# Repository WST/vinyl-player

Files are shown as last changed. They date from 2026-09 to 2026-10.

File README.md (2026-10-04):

# Мини-проигрыватель виниловых пластинок

Параметрические модели корпуса и механики небольшого проигрывателя под
7" пластинки. Всё считается в OpenSCAD, печатается на FDM-принтере.

Стадия: **прототип №0**. Принцип работы — сначала получить крутящийся диск и
играющий тонарм, потом улучшать. Поэтому здесь сознательно нет обратной связи
по скорости, микролифта и антискейтинга (см. [Отложено](#отложено)).

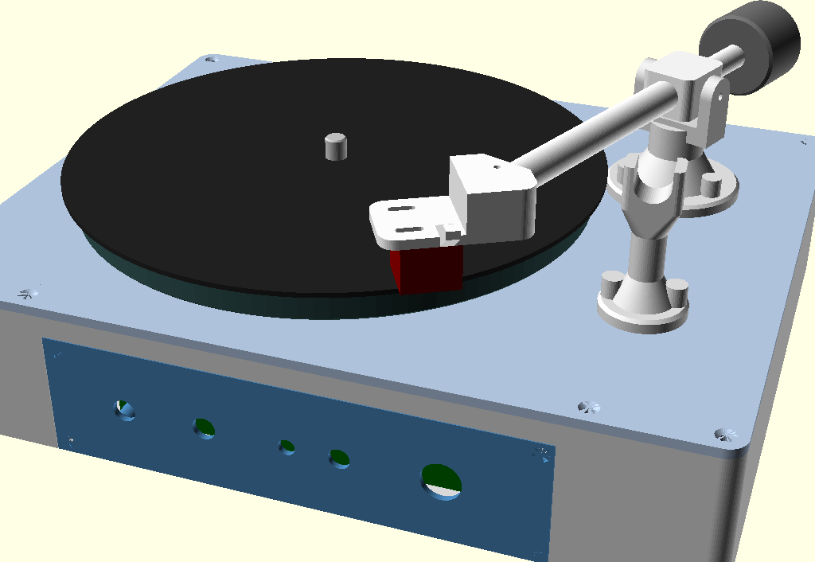
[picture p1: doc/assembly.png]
Общий вид


## Что уже заложено

| Узел | Решение |
|---|---|
| Корпус | 250 x 200 x 50 мм, стенки 2 мм, поддон + верхняя часть на саморезах |
| Скругления | только вертикальные (боковые) рёбра, R6; верх и низ — острые |
| Диск | 170 мм, только 7" пластинки |
| Модуль вращения | отдельный «плагин» на своём шасси, ставится в поддон на 4 бобышки |
| Вал диска | стальной пруток 8 мм на двух 608ZZ, конец сточен до 7.1 мм под пластинку |
| Привод | RF-300C-14270, две ступени пассиков 1.2 мм, редукция 90:1 |
| Тонарм | поворотный, эффективная длина 130 мм, головка AT91 |
| Головка | съёмная площадка: гнездо под трубку с прижимным винтом, провод протягивается |
| Панель управления | отдельная деталь-вставка в передней стенке |
| Ножки | не предусмотрены: клеятся свои |

## Геометрия (считается автоматически)

При открытии любого файла OpenSCAD печатает сводку в консоль:

```
Габарит корпуса: 250 x 200 x 50 мм
Верх диска Z=60, рабочая плоскость пластинки Z=62.6
Отсек модуля вращения: X -93..40, Y -68..86, Z 7..42
Тонарм: L=130, вынос=17.9, разворот=30.9, ось качания Z=86.6
Погрешность тонарма на r=84: -0.53 град, на r=53: -0.32 град
```

Файлы модуля вращения добавляют к этому свою сводку — см.
[Модуль вращения](#модуль-вращения).

Система координат общая для всех деталей: X — вдоль широкой стороны, Y — вдоль
глубины (минус — передняя стенка), Z — вверх от внешней плоскости дна поддона.
Поэтому `assembly.scad` — это просто перечисление деталей без сдвигов, а любая
деталь открывается отдельно и стоит «на своём месте».

В `params.scad` и `drive/drive_params.scad` есть блоки `assert`-ов: они
проверяют, что противовес не вылезает за стенку на всём ходе тонарма, что
модуль вращения не выходит из своего отсека, что колёса не задевают друг
друга и башни, что пассики есть в наборе и так далее. Если поменять параметр
«неудачно», OpenSCAD откажется рендерить и скажет, что не так.

## Файлы

```
params.scad             все размеры проекта, производные величины, проверки
lib/common.scad         вспомогательные модули (скруглённая коробка, стойки, пазы)
assembly.scad           сборка целиком + болванки плат, пластинки, головки
parts/
  tray.scad                 поддон
  top_cover.scad            верхняя часть корпуса
  control_panel.scad        панель кнопок и регуляторов
  platter.scad              диск
  tonearm_base.scad         стойка тонарма
  tonearm_pin.scad          палец вертикальной оси
  tonearm_yoke.scad         вилка
  tonearm_arm.scad          ступица + трубка + хвостовик
  tonearm_headshell.scad    съёмная площадка головки звукоснимателя
  tonearm_counterweight.scad противовес
  tonearm_rest.scad         подставка тонарма
drive/                  модуль вращения — самостоятельный «плагин»
  drive_params.scad         его параметры, производные, проверки, сводка
  drive_lib.scad            общие куски шкивов
  drive.scad                drive_module(): узел в сборе + болванки покупного
  drive_assembly.scad       превью узла отдельно от проигрывателя
  parts/
    drive_chassis.scad          шасси: плита + две башни под 608ZZ
    drive_spindle_pulley.scad   колесо вала диска
    drive_spacer.scad           шайба под ним
    drive_idler_pulley.scad     большое колесо промвала
    drive_idler_cap.scad        колпачок-бортик промвала
    drive_motor_holder.scad     держатель двигателя
```

```sh
make -j4              # все STL в build/
make build/platter.stl
make drive            # только детали модуля вращения
make check            # прогнать все модели, поймать ошибки и незамкнутость
```

## Модуль вращения

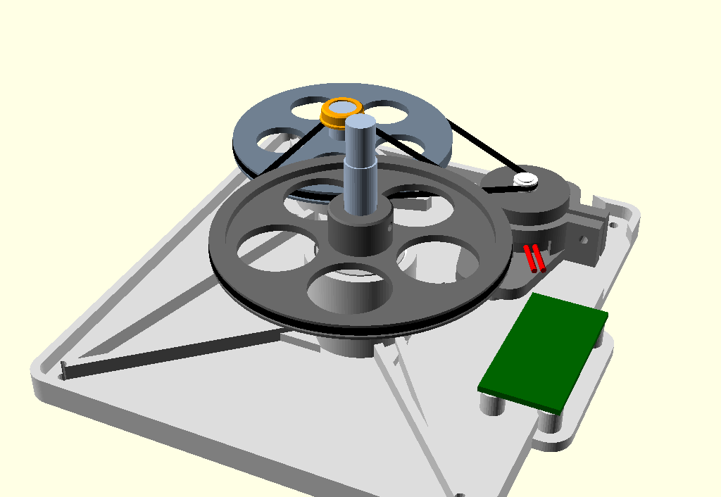
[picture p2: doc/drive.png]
Модуль вращения


### Зачем отдельный модуль

Привод — самая сырая часть проекта, её придётся переделывать много раз.
Поэтому всё, что крутит диск (вал, подшипники, колёса, двигатель), собрано на
собственном шасси и ставится в поддон как готовый узел — по аналогии с
панелью управления.

Поддон о приводе знает только **интерфейс**, он описан в `params.scad`:

* отсек `drive_bay`: от боковых стенок и передней стенки не ближе 30 мм (там
  будут динамики и плата управления), справа — до зоны тонарма и платы УМ;
* четыре бобышки `drive_mount_pos` под саморезы 2.5 x 8;
* потолок `drive_ceiling_z` — под рёбрами крышки, а в круге
  `spindle_keepout_d` вокруг вала, где рёбер нет, — почти до самой крышки;
* ось вала `platter_pos`, диаметр `spindle_d`, высота его верха.

Всё остальное живёт в `drive/`. Общая сборка вызывает только `drive_module()`
из `drive/drive.scad`. Другая реализация привода — это другая папка `drive/`
с тем же модулем и в тех же границах, поддон и крышка при этом не меняются.

Для работы с узлом есть `drive/drive_assembly.scad`: модуль в сборе, вокруг —
полупрозрачные поддон и разрешённый объём. Выключатели в начале файла:
диск сверху, разрез через оба вала и т.п.

### Кинематика

Двигатель RF-300C-14270 — около 3000 об/мин, диску нужно 33 1/3, то есть
редукция 90:1. Она разбита на две ступени:

1. **заводское колесо двигателя → большое колесо промвала** (62 мм), 11.3:1;
2. **промвал → колесо вала диска** (73.5 мм), 8:1. Здесь шкивом служит сам
   гладкий стальной промвал 8 мм, как тонвал в магнитофоне. Печатный шкив
   на валу получился бы минимум 11-12 мм — колёса выросли бы, а пассики
   перестали бы помещаться в набор.

Диаметры даны по средней линии пассика (дно канавки + толщина пассика).
Задаётся колесо промвала `idler_pulley_pd`, а колесо вала диска
пересчитывается так, чтобы при `motor_rpm` получалось ровно 33 1/3.
Межосевые и углы стоят в `drive_params.scad`, сводка при открытии любого
файла модуля:

```
Редукция: 11.3 x 8 = 90; двигатель 3000 -> промвал 266.1 -> диск 33.3 об/мин
Для 45 об/мин двигателю нужно 4050 об/мин
Колёса: промвал 62 мм (нар. 62.8), вал диска 73.5 мм (нар. 74.3)
Пассик 1: межосевое 55, путь 230.9 мм, охват 118 град -> брать ~107 по маркировке
Пассик 2: межосевое 58, путь 264.1 мм, охват 113 град -> брать ~123 по маркировке
Вал диска: пруток 8 мм длиной 66.1, сточить до 7.1 верхние 10.6 мм
Промвал: пруток 8 мм длиной 38
Плоскости пассиков: Z=31.2 и Z=36.7, дно двигателя Z=16.5 (дно держателя 3.5 мм)
```

**Пассики** — квадратные 1.2 мм из ремнабора. Маркировка таких наборов — это
«сложенная длина», половина окружности: самый большой «135» — это примерно
270 мм по кругу. Проверки требуют, чтобы оба пассика укладывались в 135 с
натягом 7 % (`belt_stretch`) и чтобы охват малых шкивов был не меньше 100
градусов. Если пассик не тянет, берётся следующий размер поменьше; первая
ступень дополнительно натягивается сдвигом держателя двигателя по пазам.

Скорость задаётся напряжением/ШИМ двигателя. Подбираются и 33, и 45 об/мин
(по стробоскопу или приложению-тахометру): двигатель допускает до 4 В, и
4050 об/мин для 45 укладываются с запасом.

### Валы и подшипники

Оба вала — отрезки стального прутка 8 мм, каждый в двух 608ZZ. Подшипники
запрессовываются в башни шасси: нижний — снизу, верхний — сверху, оба
упираются наружным кольцом в перемычку между гнёздами. Посадку гнезда правит
`brg_seat_clr`: проще напечатать пробную башню и подобрать.

Пруток проходит во внутреннее кольцо с зазором «в волос». Его надо выбрать,
иначе вал бьёт и может проворачиваться в кольце вместо подшипника. Модель
этого не решает, это делается при сборке:

1. **фольга** — один-два витка пищевой фольги (0.01-0.02 мм) на посадочном
   месте под каждым внутренним кольцом, без нахлёста по шву. Плотная посадка,
   полностью разборно — основной вариант, пока узел дорабатывается;
2. **кернение** посадочной шейки — 6-8 точек по окружности, выступы
   подогнать надфилем до тугой посадки;
3. **суперклей** — собрать насухо, выставить вал и капнуть жидкий клей на
   стык кольца с валом, его втянет в зазор. Разбирается только нагревом.

С фольгой порядок такой: вал с верхним подшипником вставляется сверху,
нижний подшипник надевается на вал снизу и запрессовывается одновременно на
вал и в гнездо — иначе фольга нижней посадки не пройдёт через верхнее кольцо.

По высоте вал зажат между двумя упорами, оба давят только на внутренние
кольца. Сверху — колесо: оно зажато на валу стопорным винтом M3 и через
шайбу `drive_spacer` (у промвала — пояском ступицы) стоит на верхнем
подшипнике. Снизу — кольцо из нескольких слоёв термоусадки под нижним
подшипником: не даёт вытянуть вал вверх, например вместе с диском. Через
верхний упор идёт и вес диска с пластинкой. Ступица колеса
поднимается в зону без рёбер крышки, поэтому винт оказывается над колесом,
и к нему есть подход сбоку. Верхний конец вала сточен до 7.1 мм: ступенька
прячется в ступице диска под матом, а сам диск зажимается своим стопорным
винтом уже на 8 мм.

У промвала колесо стоит сверху, а ступица уходит вниз, к подшипнику. Её
стопорный винт — под колесом. Над колесом — голый участок вала, по нему идёт
пассик 2. Снизу его ограничивает само колесо, сверху — напрессованный
колпачок `drive_idler_cap`. Участок вала под пассиком должен быть чистым,
без смазки — лучше слегка зашкурить для сцепления.

ZZ-подшипники с заводской смазкой заметно тормозят, а двигатель у нас
слабый (лучший КПД при ~3.8 г·см). Если не будет хватать момента — снять
пыльники с подшипников промвала, промыть их от смазки и капнуть жидкого масла.

### Двигатель

Держатель — стакан с хомутом: двигатель стоит в нём донцем, валом вверх,
обжимается стяжным винтом. Толщина дна держателя выставляет канавку
заводского колеса в плоскость пассика 1. Положение канавки
(`motor_groove_z`, 14.7 мм от донца) пока **оценочное — его надо измерить**.
Если оно другое, перепечатывается только держатель, шасси не меняется.
Провода выходят через вырез у дна стакана.

Рядом с двигателем, прямо напротив выреза под провода, на шасси стоят четыре
стойки под **плату регулятора оборотов** (около 20 x 40 мм): провода
двигателя получаются короткими и меньше наводят на звуковой тракт. Плата
вынесена из-под колеса вала диска, так что при снятой крышке к подстроечнику
можно подлезть сверху. Над платой остаётся ~24 мм под детали, под ней —
2.5 мм над рёбрами шасси под пайку выводов. Положение и отверстия задаются в
`drive_params.scad` (`reg_pcb_pos`, `reg_pcb_holes`). Отверстия по умолчанию
условные, их надо поправить под реальную плату — стойки сдвинутся, поддон
это не затрагивает. Стяжной винт хомута вворачивается со стороны, обратной
плате, чтобы плата не закрывала отвёртке подход.

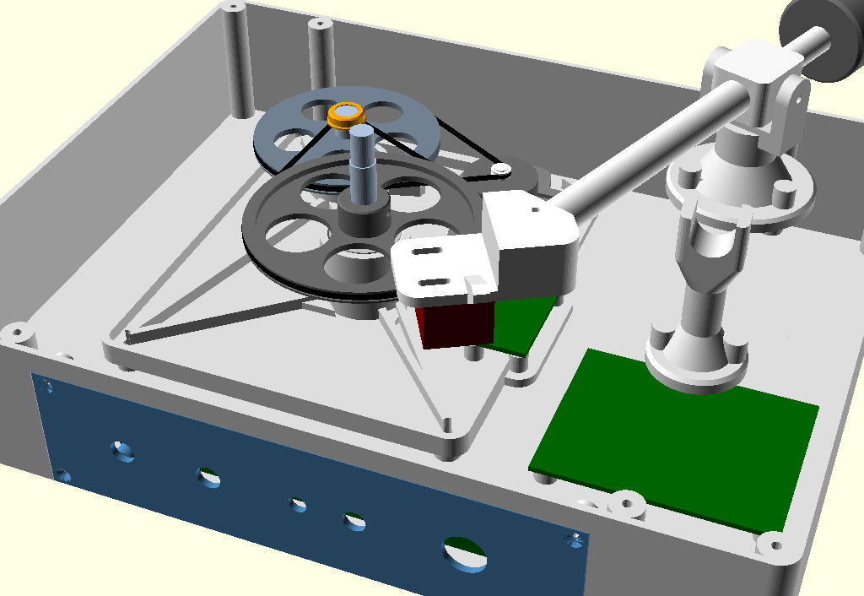
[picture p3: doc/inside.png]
Компоновка внутри


## Тонарм

Геометрия посчитана по Бервальду (Löfgren A) для рабочей зоны радиусов
53...84 мм, то есть под 7" сингл:

| Параметр | Значение |
|---|---|
| Эффективная длина (игла — ось) | 130 мм |
| Монтажное расстояние (ось — центр диска) | 112.1 мм |
| Вынос за центр диска | 17.9 мм |
| Разворот головки | 30.9 град |
| Нулевые точки | 56.0 и 77.4 мм |
| Максимальная погрешность тангенциальности | 0.57 град |

Трубка прямая, головка развёрнута. Угол между головкой и трубкой (около 40
град) и длина трубки не задаются руками, а выводятся из эффективной длины,
разворота и вылета головки — иначе при прямой трубке эти три величины
противоречат друг другу. Хочется другую длину тонарма — меняются
`arm_eff_len`, `arm_overhang`, `arm_offset_angle`, остальное пересчитается.

Кардан простейший: вертикальная ось — полый печатный палец в канале стойки со
смазкой, горизонтальная ось качания — два винта M3 с заточенными концами,
входящие в конусные гнёзда ступицы. Зазор выставляется глубиной завинчивания,
после настройки резьбу стоит зафиксировать лаком.

Площадка головки — **отдельная деталь**. Так сделано ради провода: пока
головка была единым целым с трубкой, канал оказывался заглушён её шеей и
завести провод было физически некуда. Теперь трубка открыта с торца, провод
протягивается насквозь до установки головки, а сама головка снимается — можно
поменять звукосниматель, не разбирая тонарм.

Сам стык предельно простой: на задней части площадки поднят «нарост» того же
контура, в нём наклонное гнездо под трубку, а задний угол срезан одной
плоскостью перпендикулярно трубке — это вход гнезда. Трубка входит на 9 мм до
упора в глухое дно и тянется винтом M2.5 сверху по лыске. Дно задаёт
эффективную длину, лыска — угол разворота, так что после снятия-установки
геометрия не уезжает.

Размеры площадки не выставлены руками: ширина, задний свес и высота нароста
проверяются assert'ами на то, что вход гнезда целиком лежит в контуре и что
вокруг него остаётся материал. Меняется угол разворота или диаметр трубки —
проверки скажут, что править. Подставка ловит трубку перед наростом, чтобы
вес тонарма ложился на саму трубку, а не на съёмную деталь и её винт.

Сигнальный провод от AT91 идёт внутри трубки, выходит вниз из ступицы, через
полый палец и стойку — внутрь корпуса. Со стороны головки он выходит снизу
площадки сразу позади корпуса звукоснимателя — как раз к его лепесткам.
Токосъёмных колец нет: слабина провода работает и проводником, и мягким
ограничителем поворота.

Настройка при сборке:

* **прижимная сила** — массой и положением противовеса. Стакан противовеса
  засыпается дробью или гайками М8 и заливается эпоксидкой. По расчёту масс
  печатных деталей для AT91 при VTF 2 г нужно около 37 г на вылете 45 мм, то
  есть сам стакан (~9 г) плюс ~28 г засыпки — стакан надо заполнять почти
  целиком, лучше стальной или свинцовой дробью. Точная настройка — сдвигом по
  хвостовику, ход даёт запас больше грамма VTF. Проверять весами для тонарма
  или ювелирными;
* **вынос** — пазами крепления головки, +-4 мм. Выставляется шаблоном
  (протрактор печатается отдельно или печатается на бумаге);
* **высота (VTA)** заложена жёстко: ось качания стоит на
  `игла + высота головки + площадка`. Если головка окажется другой —
  меняется `cart_height`, и стойка станет выше или ниже.

Подставка тонарма приподнимает трубку на 5 мм, чтобы игла гарантированно не
касалась ни пластинки, ни крышки. Трубка ложится в U-образное ложе со
стенками до её верха, поэтому при переноске не съезжает вбок. Вдавливать её
никуда не нужно: защёлкивание нагружало бы оси качания. Тонарм снимается
с подставки рукой за пальцевой упор — микролифта нет.

## Панель управления

Смысл этой детали — модульность, как заглушки портов в корпусах ПК: под неё в
передней стенке поддона сделано окно с четвертью (панель встаёт заподлицо) и
четыре крепёжные бобышки. Плата кнопок и регуляторов крепится к самой панельке
на четыре стойки, поэтому панель с платой снимается и ставится как один узел.

Сейчас в панели: два потенциометра (громкость + задел под тембр), светодиод,
выключатель питания и кнопка. Список отверстий — это просто массивы координат
в `params.scad` (`panel_pot_x`, `panel_btn_x`, ...). Захотелось тембр, линейный
выход или гнездо наушников — правится только панель и её плата, поддон
остаётся прежним.

## Печать

Материал: PLA или PETG. Механически нагруженные мелочи (палец, ступицы
колёс) — 100% заполнение.

| Деталь | Ориентация |
|---|---|
| Поддон | как есть, дном на стол, без поддержек |
| Крышка | перевернуть: наружной плоскостью на стол (бортик и рёбра вверх) |
| Панель управления | лицом на стол |
| Диск | перевернуть: рабочей плоскостью на стол |
| Палец тонарма | стоя, 100% заполнение |
| Шасси модуля вращения | плитой на стол, без поддержек |
| Колесо вала диска | диском на стол, ступица вверх |
| Колесо промвала | перевернуть: диском на стол, ступица вверх |
| Держатель двигателя, шайба, колпачок | как есть, плашмя |
| Стойка тонарма, подставка | основанием на стол |
| Вилка | нижней плоскостью траверсы на стол |
| Трубка тонарма | лежа: ступица на столе, под трубку лёгкие поддержки |
| Головка | площадкой на стол, наростом вверх, без поддержек |
| Противовес | стоя, открытой полостью вверх |

Крышка 250x200x3 мм сама по себе «играет», поэтому снизу у неё сетка рёбер
жёсткости с вырезами под стойки поддона и крепёж тонарма.

## Крепёж и покупное

* саморезы с потайной головкой 3 x 12 — 8 шт (крышка к поддону);
* саморезы 2.5 x 10 — 4 шт (панель), 2.5 x 12 — 5 шт (стойка и подставка
  тонарма вкручиваются изнутри корпуса), 2.5 x 8 — 4 шт (плата), ещё 2.5 x 8
  — 6 шт (шасси модуля вращения к поддону и держатель двигателя к шасси),
  2.5 x 6 — 4 шт (плата регулятора оборотов);
* саморез 3 x 16 — стяжка хомута держателя двигателя;
* винты M3: 2 шт с заточенным концом (оси качания), 4 шт стопорных (два
  колеса модуля вращения, ступица диска, противовес);
* двигатель RF-300C-14270 с заводским колесом;
* подшипники 608ZZ — 4 шт, стальной пруток 8 мм (~66 + ~38 мм), термоусадка
  на упорные кольца, пищевая фольга на посадку вала в подшипники;
* пассики квадратные 1.2 мм, ~107 и ~123 по маркировке (см. сводку модуля);
* винт M2.5 x 8 — прижимной для гнезда трубки в головке;
* головка звукоснимателя Audio-Technica AT91, крепёж 1/2" винтами M2 (пазы
  площадки сделаны под M2: под M2.5 головка винта почти проваливается в паз);
* мат на диск: войлок или резина, диаметр 164 мм, толщина 2 мм;
* густая смазка для вертикальной оси тонарма;
* дробь или гайки М8 и эпоксидка — засыпка противовеса.

## Порядок сборки

1. Собрать модуль вращения отдельно, на столе: отрезать валы по сводке,
   сточить конец вала диска до 7.1 мм. Верхние подшипники посадить на валы
   (с фольгой) и запрессовать в башни сверху, нижние надеть на валы снизу и
   запрессовать в гнёзда. Под нижними подшипниками усадить на вал упорные
   кольца из термоусадки, прижимая их к внутреннему кольцу.
2. Вал диска: надеть шайбу и колесо, поджать колесо к подшипнику (выбрать
   осевой люфт) и затянуть стопорный винт. Промвал: так же, колесо поясом
   ступицы к подшипнику, винт, колпачок на верхний конец.
3. Двигатель — в держатель, стянуть хомут, держатель на шасси. Плату
   регулятора — на стойки рядом, провода двигателя к ней покороче. Накинуть
   оба пассика, натянуть первый сдвигом держателя по пазам. Проверить
   вращение прямо на столе. Готовый модуль поставить в поддон на четыре
   самореза.
4. Поставить платы: фонокорректор/УМ на стойки в поддоне, плату управления —
   на панельку; панельку завести в окно передней стенки.
5. К крышке снизу привинтить стойку тонарма и подставку.
6. Протянуть сигнальный провод: с открытого торца трубки к ступице и вниз
   через её отверстие — с запасом на оба конца. Головку пока не ставить,
   иначе провод не завести.
7. Собрать тонарм: палец в вилку (с натягом), вилку — в стойку, ступицу — в
   вилку на винтах-осях, выставить зазор качания; нижний конец провода
   спустить через палец и стойку внутрь корпуса, оставив слабину на весь
   ход поворота.
8. Припаять верхний конец к лепесткам AT91, надеть головку на трубку до
   упора в дно гнезда, затянуть прижимной винт по лыске, привинтить головку
   в пазы.
9. Закрыть крышку восемью саморезами, надеть диск на вал, зафиксировать
   стопорным винтом через отверстие в ободе, положить мат.
10. Настроить прижимную силу и вынос, подобрать обороты.

## Отложено

Сознательно не сделано на этом этапе, но место под это есть или будет:

* **динамик** — будет где-то в корпусе, посадочное место ещё не выбрано;
* **батарейный отсек** — тоже отдельная задача, вместе с выбором питания;
* **микролифт тонарма** — возможная доработка, пока подъём рукой;
* **обратная связь по скорости вращения** — пока разомкнутая схема, обороты
  подбираются напряжением/ШИМ;
* **антискейтинг** — на прототипе нет;
* **виброразвязка двигателя** — держатель пока жёстко на шасси;
* **пылезащитная крышка** — не проектировалась;
* **регулировка VTA** — высота оси качания задана расчётом, без механизма;
* **подшипники в вертикальной оси тонарма** — MR106 вместо печатного канала;
* **разъёмы на задней стенке** (линейный выход, питание) — появятся вместе с
  питанием и усилителем;
* **протрактор** для выставления выноса — напечатать отдельной деталью.

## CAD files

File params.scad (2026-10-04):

// ============================================================================
//  Мини-проигрыватель виниловых пластинок (7", 33 1/3 об/мин)
//  ОБЩИЙ ФАЙЛ ПАРАМЕТРОВ — единственное место, где задаются размеры.
//
//  Все линейные размеры в миллиметрах, углы в градусах.
//
//  Система координат (общая для всех деталей и для сборки):
//    X — вдоль широкой стороны корпуса (250 мм), 0 — середина
//    Y — вдоль глубины корпуса (200 мм), 0 — середина, -Y — «передок»
//    Z — вверх, 0 — внешняя плоскость дна поддона
//
//  Каждая деталь описана в СВОИХ координатах сборки, т.е. если открыть
//  assembly.scad, всё стоит на своих местах без дополнительных сдвигов.
//  Для печати детали разворачиваются в Makefile/слайсере.
// ============================================================================

// ---------------------------------------------------------------- рендер ----
$fa = 3;      // максимальный угол фрагмента
$fs = 0.6;    // минимальный размер фрагмента
eps = 0.01;   // технологический «нахлёст» для булевых операций

// ============================================================================
//  КОРПУС
// ============================================================================
case_w = 250;           // габарит по X
case_d = 200;           // габарит по Y
case_h = 50;            // габарит по Z (поддон + крышка, без диска)

wall     = 2;           // толщина стенок
floor_t  = 2;           // толщина дна поддона
corner_r = 6;           // скругление ВЕРТИКАЛЬНЫХ (боковых) рёбер;
                        // нижние и верхние рёбра оставляем острыми

cover_plate_t = 3;      // толщина верхней панели
cover_lip_h   = 5;      // высота бортика, входящего внутрь поддона
cover_lip_t   = 1.6;    // толщина этого бортика
cover_lip_clr = 0.3;    // зазор бортика по стенкам поддона
cover_rib_t   = 2;      // рёбра жёсткости на изнанке крышки
cover_rib_h   = 4;
cover_rib_pitch = 45;
cover_spindle_hole_d = 12;  // проём в крышке вокруг вала

// ------------------------------------------------------------------ крепёж --
// Корпусные саморезы 3.0 x 12 с потайной головкой
scr3_pilot  = 2.5;      // отверстие «под вкручивание»
scr3_free   = 3.3;      // проходное отверстие
scr3_head_d = 5.8;
scr3_boss_d = 9;
scr3_depth  = 11;       // глубина пилотного отверстия в стойке

// Мелкие саморезы 2.5 x 10 (панель управления, платы, тонарм)
scr25_pilot  = 2.1;
scr25_free   = 2.8;
scr25_head_d = 5.0;
scr25_boss_d = 6.5;
scr25_depth  = 9;

// ============================================================================
//  ПАНЕЛЬ УПРАВЛЕНИЯ (съёмная, в передней стенке поддона)
//  Идея: хотим добавить тембр/линейный выход/наушники — переделываем
//  только эту деталь и её плату, поддон не трогаем.
// ============================================================================
panel_w = 140;          // окно в стенке по X
panel_h = 26;           // окно в стенке по Z
panel_z = 20;           // высота центра окна над столом
panel_t = 2;            // толщина самой панельки
panel_flange = 7;       // заплечик панельки (нахлёст на рамку поддона)
panel_clr = 0.25;       // зазор панельки в рамке
panel_pad_t = 2.5;      // местное утолщение стенки изнутри вокруг окна
panel_pad_w = 12;       // на сколько это утолщение выходит за окно
panel_scr_off = 3.5;    // центр крепёжного винта от кромки окна
panel_boss_len = 6;     // вылет крепёжной бобышки внутрь корпуса

// Элементы управления: X — от центра панели, все на средней линии окна.
// Менять здесь — это и есть «доработка панельки».
panel_pot_d  = 7.2;     // резьбовая шейка потенциометра 6 мм
panel_pot_x  = [-52, -26];   // громкость, задел под тембр
panel_led_d  = 5.2;
panel_led_x  = [0];
panel_sw_d   = 6.6;     // тумблер/кнопка питания
panel_sw_x   = [16];
panel_btn_d  = 12.2;    // кнопка «стоп/старт»
panel_btn_x  = [46];

// Плата кнопок и регуляторов крепится к самой панельке
panel_pcb      = [120, 20];
panel_pcb_h    = 8;         // высота стоек (зазор панель → плата)
panel_pcb_hole = [[-54, -6], [54, -6], [-54, 6], [54, 6]];

// ============================================================================
//  ДИСК И ВАЛ
//  Всё, что под крышкой (подшипники, шкивы, двигатель), — это модуль
//  вращения в drive/. Здесь только то, что видят остальные детали:
//  где ось, какого диаметра вал и как высоко он торчит.
// ============================================================================
platter_d   = 170;          // поддерживаются только 7" пластинки
platter_h   = 9;
platter_pos = [-25, 0];     // ось вращения в плане (смещена влево, справа тонарм)
platter_gap = 1.0;          // зазор между диском и крышкой корпуса
platter_top_t  = 3;         // толщина рабочей плоскости диска
platter_rim_t  = 2.5;       // толщина обода
platter_hub_d  = 16;
platter_hub_h  = 9;         // ступица не должна выступать над плоскостью диска
platter_spokes = 6;
platter_mat_d  = 164;       // утопление под мат (войлок/резина)
platter_mat_recess = 1.0;
mat_t = 2;                  // толщина мата (в расчёте высоты тонарма)

record_d      = 178;        // 7" пластинка (для сборки/проверок)
record_t      = 1.6;
record_hole_d = 7.3;

// Вал — стальной пруток 8 мм. Верхний конец сточен до 7.1 мм: он же
// центрирующий штырь под отверстие пластинки.
spindle_d     = 8;
spindle_tip_d = 7.1;
spindle_above_record = 7;   // сколько вал выступает над пластинкой
set_access_d = 4.5;         // технологические отверстия к стопорным винтам

platter_rpm = 33.333;

// ============================================================================
//  МОДУЛЬ ВРАЩЕНИЯ: ИНТЕРФЕЙС С ПОДДОНОМ
//  Модуль (вал, подшипники, редукция, двигатель) — отдельный «плагин» в
//  drive/, ставится в поддон на четыре бобышки. Поддон знает только то,
//  что ниже: отсек, точки крепления и потолок. Переделка привода — это
//  правка drive/, поддон и крышка при этом не меняются.
// ============================================================================
// Отсек: за боковыми стенками будут динамики, за передней — плата
// управления, поэтому от них держим не меньше 30 мм. Справа — тонарм и
// плата УМ, сзади — место под будущие разъёмы.
drive_keep_side  = 30;
drive_keep_front = 30;
drive_keep_back  = 12;
drive_bay_x1     = 40;

// Бобышки под шасси модуля: саморезы 2.5 x 8 сверху через шасси
drive_mount_pos    = [[-82, -50], [22, -50], [-82, 72], [22, 72]];
drive_mount_boss_d = 8;
drive_mount_boss_h = 5;

// Вокруг вала крышка без рёбер — там модулю можно подниматься почти
// до самой крышки (ступица колеса со стопорным винтом)
spindle_keepout_d = 32;

// ============================================================================
//  ТОНАРМ
//  Геометрия рассчитана по Бервальду (Löfgren A) для рабочей зоны
//  радиусов 53…84 мм (7" сингл): нулевые точки 56.0 и 77.4 мм,
//  максимальная погрешность тангенциальности 0.57°.
//  Головка звукоснимателя — Audio-Technica AT91 (1/2", 2 винта M2.5).
// ============================================================================
arm_groove_r_in  = 53;      // внутренний радиус фонограммы
arm_groove_r_out = 84;      // внешний радиус фонограммы
arm_eff_len      = 130;     // эффективная длина: игла → вертикальная ось
arm_overhang     = 17.9;    // заход иглы за ось диска
arm_offset_angle = 30.9;    // разворот головки
arm_azimuth      = 21;      // где стоит стойка относительно оси диска
                            // (подобран так, чтобы противовес не вылезал
                            //  за заднюю стенку на всём ходе тонарма)

cart_height   = 16;         // AT91: посадочная плоскость → кончик иглы
cart_body     = [17, 17.5, 16];  // габарит для проверки в сборке (Ш x Д x В)
cart_screw_spacing = 12.7;  // стандарт 1/2"
cart_screw_d  = 2.3;        // под винты M2 (головка M2 через паз не проходит)
cart_slot_len = 8;          // пазы регулировки выноса
cart_stylus_to_holes = 9.5; // от иглы до линии крепёжных отверстий

arm_tube_od   = 10;
arm_tube_id   = 6.4;        // канал сигнального провода AT91 (4 жилы)
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

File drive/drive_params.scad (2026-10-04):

// ============================================================================
//  МОДУЛЬ ВРАЩЕНИЯ — ПАРАМЕТРЫ
//
//  Самостоятельный узел («плагин»): шасси с двумя стальными валами на
//  подшипниках 608ZZ, двухступенчатая пассиковая редукция и двигатель
//  RF-300C-14270. Ставится в поддон на бобышки drive_mount_pos.
//  Поддон и крышка от этого файла не зависят — они видят только интерфейс
//  в ../params.scad (отсек, точки крепления, потолок, ось и диаметр вала).
//
//  Кинематика:
//    двигатель, заводское колесо --пассик 1--> большое колесо промвала
//    промвал, сам стальной вал как шкив --пассик 2--> колесо вала диска
//
//  Система координат — общая для всего проекта (см. ../params.scad).
// ============================================================================

include <../params.scad>

// ------------------------------------------------------------ двигатель ----
// RF-300C-14270 (Mabuchi): 1.9 В ном. (0.5...4 В), ~3500 об/мин без
// нагрузки, ~2700 под нагрузкой. Колесо под пассик стоит с завода.
motor_d         = 24.5;
motor_h         = 13;       // корпус без колеса
motor_full_h    = 16.35;    // вместе с колесом
motor_groove_d  = 4.3;      // дно канавки заводского колеса
// Середина канавки над донцем двигателя — ОЦЕНКА, уточнить штангенциркулем.
// От неё зависит только толщина дна держателя двигателя.
motor_groove_z  = 14.7;
motor_pulley_od = 6.5;      // только для болванки
motor_rpm       = 3000;     // рабочие обороты, под них считается редукция
motor_bump_d    = 8;        // выемка под выступ подшипника на донце
motor_bump_h    = 1.5;
motor_wire_angle = -60;     // вырез под провода (0 — направление «от промвала»)

// --------------------------------------------------- подшипники 608ZZ ------
brg_od = 22;
brg_id = 8;
brg_w  = 7;
brg_inner_ring_d = 11.5;    // упор только во внутреннее кольцо
brg_outer_ring_d = 19.6;    // упор только в наружное кольцо
brg_seat_clr     = 0.15;    // посадка в печатное гнездо — подобрать под принтер

// --------------------------------------------------------------- пассики ---
// Квадратные 1.2 мм из ремнабора. Маркировка набора — «сложенная длина»,
// то есть половина окружности: самый большой «135» — это ~270 мм по кругу.
belt_t          = 1.2;
belt_max_folded = 135;
belt_stretch    = 0.07;     // натяг: пассик короче своего пути на 7 %
belt_min_wrap   = 100;      // минимальный охват малого шкива, град
belt_side_clr   = 0.6;      // свободный ход пассика по высоте

// ----------------------------------------------------------- компоновка ----
// Промвал стоит за осью диска: спереди и слева отсек упирается в резерв
// под плату управления и динамик. Двигатель — правее промвала.
idler_dist      = 58;       // межосевое: вал диска -> промвал
idler_angle     = 120;      // направление от оси диска, град
motor_dist      = 55;       // межосевое: промвал -> двигатель
motor_angle     = 0;        // направление от промвала
idler_pulley_pd = 62;       // большое колесо промвала, по средней линии пассика
// Рабочий участок промвала под пассиком 2. Если проточить его тоньше,
// колесо на валу диска пересчитается меньше.
capstan_d       = spindle_d;

// --------------------------------------------------------------- шасси -----
chassis_t     = 3;          // плита
chassis_r     = 6;          // скругление углов плиты
chassis_ear   = 7;          // поле плиты вокруг бобышек поддона
chassis_rib_t = 2.4;        // рёбра жёсткости
chassis_rib_h = 4;
tower_wall    = 3;          // стенка вокруг подшипника
tower_mid_t   = 1;          // минимальная перемычка между гнёздами
tower_gusset  = 9;          // косынки у основания башен

// ------------------------------------------------- держатель двигателя -----
holder_boss_d    = 8;       // бобышки шасси под держатель
holder_boss_h    = 3;
holder_wall      = 2.4;     // стенка стакана
holder_cup_h     = 9;       // сколько стакан охватывает корпус двигателя
holder_clr       = 0.4;
holder_foot_span = 46;      // между пазами крепления
holder_slot_len  = 8;       // ход регулировки натяжения пассика 1
holder_ear       = 8;       // уши стяжного винта

// ------------------------------------------- плата регулятора оборотов -----
// Вплотную к двигателю, напротив выхода его проводов: провода мотора
// короткие и меньше наводят. Не под колесом вала диска — подстроечник
// доступен сверху при снятой крышке.
reg_pcb        = [20, 40];      // габарит платы по X и Y
reg_pcb_pos    = [24, 1];       // центр платы
reg_pcb_t      = 1.6;
// Крепёжные отверстия платы от её центра — поправить под реальную плату
reg_pcb_holes  = [[-7, -17], [7, -17], [-7, 17], [7, 17]];
reg_standoff_d = 6;
reg_solder_clr = 2.5;           // под пайкой выводов над рёбрами шасси
reg_pad_margin = 3;             // поле плиты шасси вокруг платы

// --------------------------------------------------------------- шкивы -----
pulley_t        = 4;        // высота обода
pulley_groove_h = 1.0;      // глубина канавки
pulley_rim_w    = 4;        // ширина обода
pulley_web_t    = 2;
pulley_hub_d    = 16;
pulley_clr      = 1.5;      // по высоте между колёсами, перекрывающимися в плане
rod_bore_clr    = 0.2;      // посадка колёс на вал (держит стопорный винт)
hub_set_h       = 6.2;      // участок ступицы под стопорный винт M3
thrust_ring_h   = 0.5;      // упорный поясок ступицы по внутреннему кольцу
spacer_t        = 1.2;      // шайба между колесом вала диска и подшипником
cap_h           = 4.1;      // колпачок-бортик на верхнем конце промвала
cap_d           = 13;
cap_fit         = 0;        // натяг посадки колпачка (печатное отверстие и так «садится»)
// Упор вала вверх: кольцо из нескольких слоёв термоусадки на валу под
// нижним подшипником, упирается только во внутреннее кольцо
stop_ring_h     = 3;
stop_ring_d     = 10;
rod_bottom_gap  = stop_ring_h + 0.5;   // насколько валы выступают под шасси

// ============================================================================
//  ПРОИЗВОДНЫЕ (не редактировать)
// ============================================================================
function polar(c, r, a) = [c[0] + r*cos(a), c[1] + r*sin(a)];

spindle_pos = platter_pos;
idler_pos   = polar(spindle_pos, idler_dist, idler_angle);
motor_pos   = polar(idler_pos, motor_dist, motor_angle);

// ---- редукция (диаметры — по средней линии пассика) ----
motor_pd    = motor_groove_d + belt_t;
capstan_pd  = capstan_d + belt_t;
ratio_total = motor_rpm / platter_rpm;
ratio1      = idler_pulley_pd / motor_pd;
ratio2      = ratio_total / ratio1;
spindle_pulley_pd = capstan_pd * ratio2;
idler_rpm   = motor_rpm / ratio1;

function pulley_od(pd) = pd - belt_t + 2*pulley_groove_h;
idler_pulley_od   = pulley_od(idler_pulley_pd);
spindle_pulley_od = pulley_od(spindle_pulley_pd);

// ---- высоты ----
// Считаются сверху вниз: всё упирается в рёбра крышки (drive_ceiling_z).
chassis_z0 = drive_floor_z;
chassis_z1 = chassis_z0 + chassis_t;

idler_rod_top_z   = drive_ceiling_z - 0.5;
cap_z0            = drive_ceiling_z - cap_h;
belt2_z           = cap_z0 - belt_side_clr - belt_t/2;    // плоскость пассика 2
spindle_pulley_z0 = belt2_z - pulley_t/2;
spindle_tower_top = spindle_pulley_z0 - spacer_t;
spindle_hub_top   = drive_spindle_ceiling_z;
spindle_set_z     = (spindle_pulley_z0 + pulley_t + spindle_hub_top)/2;

idler_pulley_z1   = spindle_pulley_z0 - pulley_clr;       // верх колеса промвала
idler_pulley_z0   = idler_pulley_z1 - pulley_t;
belt1_z           = idler_pulley_z1 - pulley_t/2;         // плоскость пассика 1
idler_tower_top   = idler_pulley_z0 - hub_set_h - thrust_ring_h;
idler_set_z       = idler_tower_top + thrust_ring_h + hub_set_h/2;

motor_base_z  = belt1_z - motor_groove_z;
holder_z0     = chassis_z1 + holder_boss_h;
holder_base_t = motor_base_z - holder_z0;

rod_bottom_z    = chassis_z0 - rod_bottom_gap;
spindle_rod_len = spindle_top_z - rod_bottom_z;
spindle_tip_len = spindle_top_z - spindle_tip_z;
idler_rod_len   = idler_rod_top_z - rod_bottom_z;

// ---- шасси ----
tower_od = brg_od + 2*tower_wall;
seat_d   = brg_od + brg_seat_clr;
chassis_x0 = min([for (p = drive_mount_pos) p[0]]) - chassis_ear;
chassis_x1 = max([for (p = drive_mount_pos) p[0]]) + chassis_ear;
chassis_y0 = min([for (p = drive_mount_pos) p[1]]) - chassis_ear;
chassis_y1 = max([for (p = drive_mount_pos) p[1]]) + chassis_ear;

// ---- держатель двигателя ----
holder_cup_id = motor_d + holder_clr;
holder_cup_od = holder_cup_id + 2*holder_wall;
holder_boss_pos = [ for (s = [-1, 1]) polar(motor_pos, holder_foot_span/2, motor_angle + 90*s) ];
holder_foot_d = holder_boss_d + 4;
// Лапа при сдвиге держателя на весь ход паза уходит от центра на slot_len
holder_keepout_r = norm([holder_slot_len, holder_foot_span/2]) + holder_foot_d/2 + 1;
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

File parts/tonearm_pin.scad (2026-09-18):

// ============================================================================
//  ОСЬ ВЕРТИКАЛЬНОГО ПОДШИПНИКА ТОНАРМА (палец)
//
//  Сделана отдельной деталью не из любви к деталям, а ради печати:
//  так и палец, и вилка печатаются в идеальной ориентации без поддержек,
//  а рабочая поверхность пальца выходит круглой.
//  Запрессовывается в вилку, работает в канале стойки (со смазкой).
//  Полый — внутри проходит сигнальный провод.
//
//  Хороший апгрейд: заменить отрезком стальной трубки 8x1.5 мм.
//
//  Печать: стоя, 100% заполнение.
// ============================================================================

include <../params.scad>
use <../lib/common.scad>

module tonearm_pin() {
    translate([arm_pivot_pos[0], arm_pivot_pos[1],
               arm_pillar_top_z + arm_yoke_bar_t - arm_pin_len])
        difference() {
            chamfered_cyl(arm_pivot_shaft_d, arm_pin_len, ch = 0.5);
            thru(arm_pivot_wire_d, arm_pin_len);
        }
}

tonearm_pin();

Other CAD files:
drive/parts/drive_spindle_pulley.scad
assembly.scad
drive/drive.scad
drive/drive_assembly.scad
drive/drive_lib.scad
drive/parts/drive_chassis.scad
drive/parts/drive_idler_cap.scad
drive/parts/drive_idler_pulley.scad
drive/parts/drive_motor_holder.scad
drive/parts/drive_spacer.scad
parts/control_panel.scad
parts/platter.scad
parts/tonearm_arm.scad
parts/tonearm_base.scad
parts/tonearm_counterweight.scad
parts/tonearm_headshell.scad
parts/tonearm_rest.scad
parts/tonearm_yoke.scad
parts/top_cover.scad
parts/tray.scad

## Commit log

2026-10-03 Tonearm rest: U-shaped cradle keeps the parked arm in place when carried
    [params.scad, tonearm_rest.scad]
2026-10-04 Remove old printed drive parts (bushing, spindle, pulleys, motor mount)
    [bushing.scad, motor_mount.scad, motor_pulley.scad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]
2026-10-04 Drive module: standalone plugin with 608ZZ shafts and two-stage belt reduction
    [assembly.scad, drive.scad, drive_assembly.scad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]
2026-10-04 Drive module: mount for speed regulator board next to the motor
    [drive.scad, drive_chassis.scad, drive_motor_holder.scad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]
2026-10-17 Support printed shafts and TPU mat
    Migrate the drive from steel rods to printable shafts and add a TPU platter mat. New files: drive/parts/drive_spindle_shaft.scad, drive/parts/drive_idler_shaft.scad and parts/mat.scad implement print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
2026-10-17 Add mainboard.dip and update mainboard.dch
    Add new binary schematic file schematics/mainboard.dip and apply binary updates to schematics/mainboard.dch. These changes add the mainboard .dip file to the repository and modify the existing .dch s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
2026-10-18 Update mainboard schematic (mainboard.dip)
2026-10-18 Adjust shaft print compensation and set-screw options
    Update printed-shaft sizing and assembly options: invert rod_print_clr to -0.2 based on print measurements (Ø7.8 loose, Ø8.3 too tight) and treat wheel bores as nominal 8 mm (rod_bore_clr = 0). Add rod_set_screws flag (false by default) to disable set‑screw features for PLA+glue builds and gate generation of flats/holes and related asserts. Propagate these changes into drive parts (idler cap, idler pulley, spindle pulley, spindle/shaft) to use spindle_d for bores and conditionally create set-screw geometry. Update params, echo outputs and README notes/numbers to reflect measured dimensions, belt lengths and revised assembly guidance.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
2026-10-18 Add side-wall speakers and move the amp board forward
    Keep the incoming printed-shaft/TPU work; speakers drop into wall slots and the phono/amp PCB sits up front, away from the motor wires.
2026-10-18 Add clearance for idler shaft rings
    Give the spacer and idler cap a separate 0.1 mm bore clearance for a freer fit on the spindle. Hide the bay volume in the default assembly view.
2026-10-19 Replace noisy idler 608s with a printed well bushing
    The idler shaft now drops into a greased cup in the chassis; fit is idler_bush_clr so a tight or loose print is fixed by reprinting the chassis. Platter bearings stay as they are.
2026-10-20 Seat the platter on a shaft shoulder so it lifts off
2026-10-21 Make the idler well a plain cylinder without a grease pocket
2026-10-21 Tune idler shaft fit clearances
    Adjust the idler bushing and wheel bores to match print-fit iterations, and use `is_undef()` when selecting the shaft bottom position.
2026-10-22 Lower the tonearm rest so the parked arm sits level
2026-10-22 Move the speakers 30 mm toward the front
2026-10-22 Fix the I/O panel rebate and bosses, add glue-on TPU feet
2026-10-22 Size platter washer to clear cover opening
    Add a configurable 10 mm washer diameter, validate that it fits inside the cover opening and over the spindle, and update the washer model and documentation.
